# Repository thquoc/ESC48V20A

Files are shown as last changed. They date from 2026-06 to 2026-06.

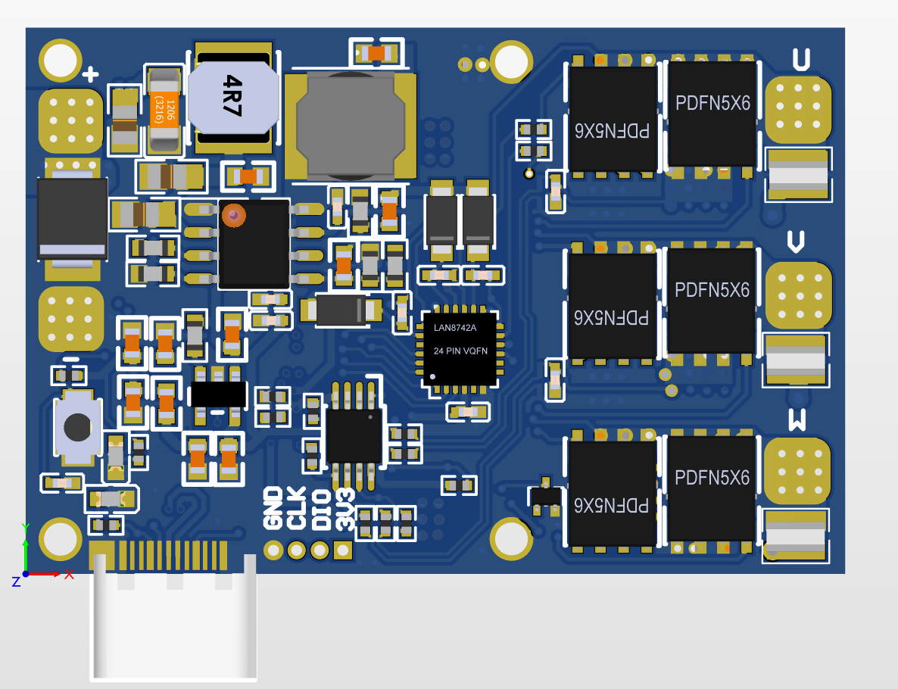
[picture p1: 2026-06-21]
3D-TOP.png

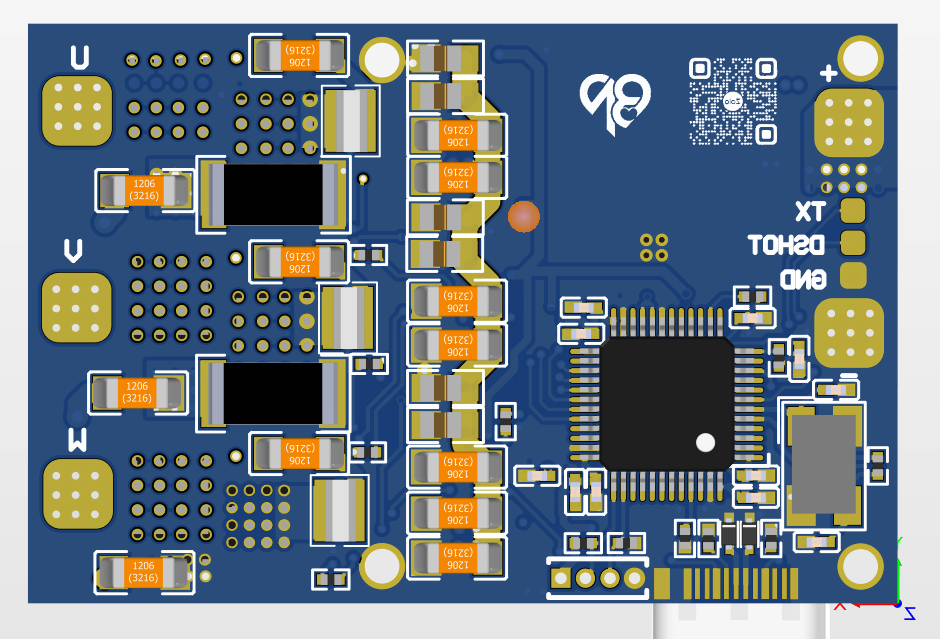
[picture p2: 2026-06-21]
3D-BOT.png

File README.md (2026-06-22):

| Thông số |Tham chiếu  | Giá trị |
|-----|---|---|
| Supply Voltage  | PVDD | 48V |
| Current | Dòng liên tục | 20A |
| IMAX | Dòng đỉnh khi kẹt tải  | 40A |
| Sense registor | Rsense | 2mΩ |
| Mosfet Qg(type)  | Qg | 60nC |
| Mosfet Rds  | Rds | 2.8mΩ tại 25℃ |
|Switching frequency| fsw | 20kHz |
|Gate resistance| Rgate | 16Ω |
|Amplifier reference| Vref | 3.3V|
|Amplifier gain| Gain | 20v/V |

------------------------------------------------------------------------------------
Note: Bạn thay đổi điện trở của ompap để có giá trị gain 20v/v. Thay Rsense = 2mΩ để cân bằng giữa nhiệt và sai số do nhiễu. Trong Documentation mình có đề cập đến cách ước tính.

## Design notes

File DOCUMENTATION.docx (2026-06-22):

DOCUMENTATION

1. Tính Rshunt để nhiệt lượng tỏa ra là thấp nhất nhưng vẫn đủ độ phân giải cho FOC.
- Dòng đo tối đa 40A, dòng liên tục 20A.
- I_(LSB) =(v_(ref))/(2^12 *Gain* R_(shunt))
- R_(shunt) =(V_(ref))/(2*I_(max) *Gain)
- Để đo dòng hai chiều trong động cơ 3 phase(dòng -, và +) tại Vref = 3.3V, ta chọn Voffset = 1.65V.

Tính tổn hao trên điện trở shunt: P = Irms^2 *Rshunt = 20*Rshunt.

- Tại Gain = 10, Rshunt = 5mΩ, P = 2W
- Tại Gain = 20, Rshunt = 2mΩ, P = 0.8W.
- Tại Gain = 40, Rshunt = 1mΩ, P = 0.4W.
- Để tối ưu về nhiệt, và sai số do nhiễu mình chọn Gain tại 20 và Rshunt = 2mΩ
2. Ước lượng nội trở Rds tối đa cho phép để mạch không quá nhiệt khi hoạt động liên tục.
- P tổn hao(Ptot) = P tổn hao dẫn(Pcond) + P chuyển mạch (Psw). Ở đây để tính Psw mình cần các giá trị cụ thể như Qg, Qrr, tf, tr... của một mosfet cụ thể. Nên trong trường hợp này ta chỉ ước lượng tương đối. Sau khi đã chọn được mosfet thích hợp mình sẽ tính lại Psw, sau đó sẽ đưa ra phương án tản nhiệt trên pcb cho mosfet.

Bảng ước lượng nhanh:

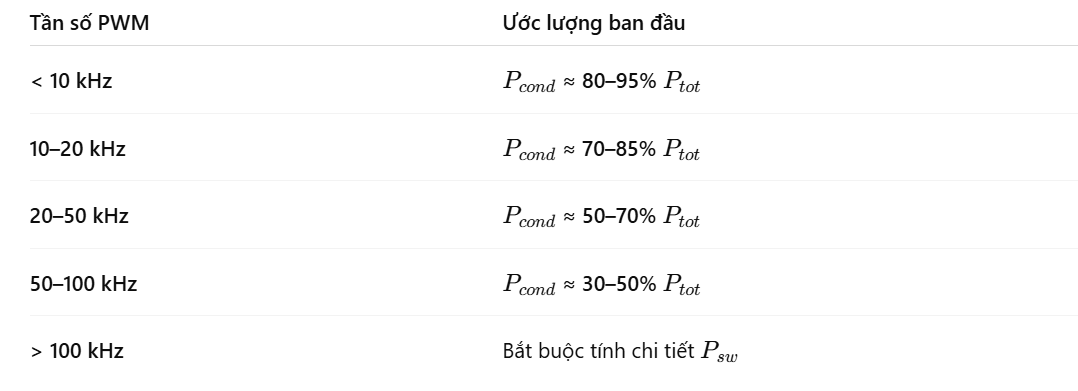
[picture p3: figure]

(Cái này mình tham khảo chat nha)

- Tại tần số 20khz, Pcond = 80% Ptot, Ptot = Pcond/0.75= (Rds.Irms^2)/0.75.

Moset không quá nhiệt khi hoạt động liên tục đối với esc drone:

- Ta = 40 độ C.
- Tj = 90 độ C.
- RθJA = 25 ℃/W(giá trị ước lượng).
- Ptot = ∆T/ RθJA = 50/25 = 2W, suy ra Pcond khoảng 1.4W.
- Rds(90) = Pcond/Irms^2 = 1.4/20^2 = 4mΩ.

Bảng ước lượng KT:

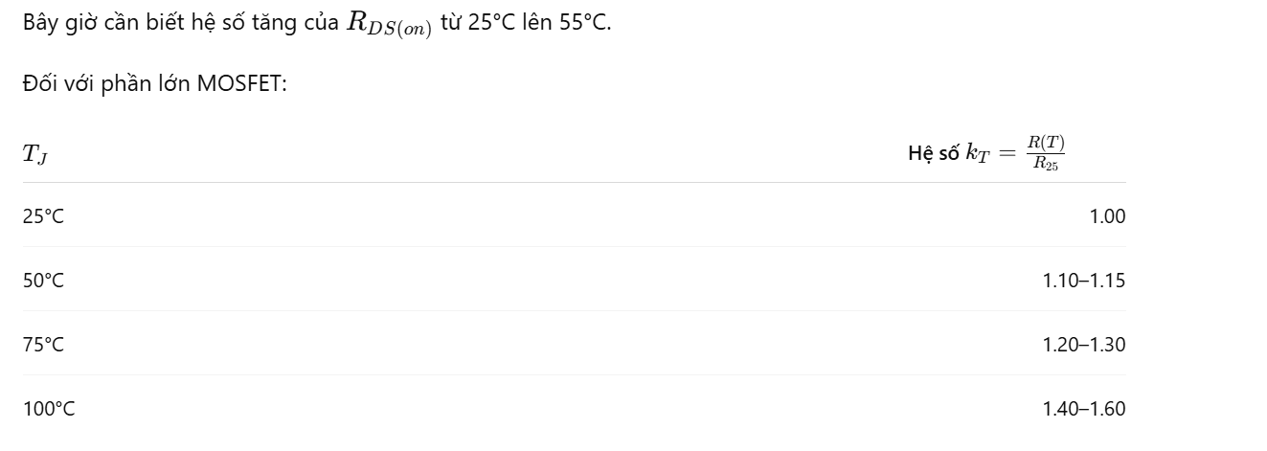
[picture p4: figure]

(Cái này mình cũng tham khảo chat nha).

- Rds(25) = R(90)/KT= 4/1.4 = 2.86mΩ, suy ra, Rds(25) max khoảng 2.9mΩ.
3. Ước lượng Dboot.

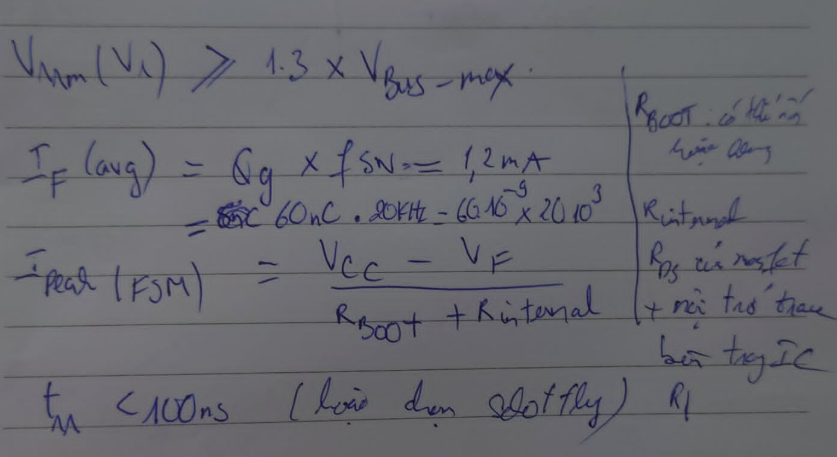
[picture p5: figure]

4. Tính Cboot cho drv.
- Tính ∆Vbst:

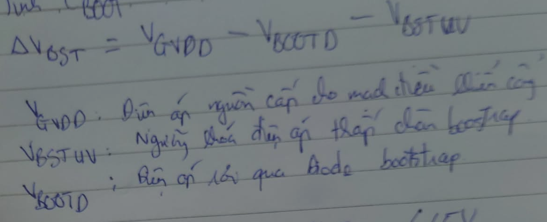
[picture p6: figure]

- ∆Vbst = 12 – 0.85 -4.5 = 6.65V.
- Qtotal:

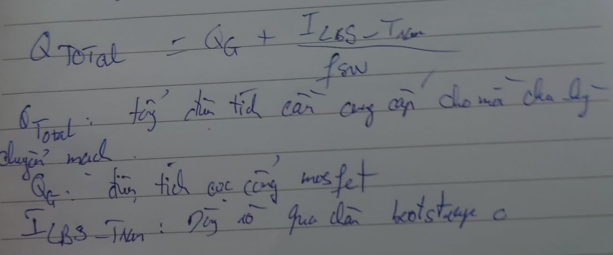
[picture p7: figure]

- Qtotal = 60nC + 11nC = 71nC
- Tính Cboot

Note: Các bước tính Psw các bạn tham khảo trong tài liệu này: infineon-70-41484-applicationnotes. Tài liệu này mình lưu trong mục datasheet.

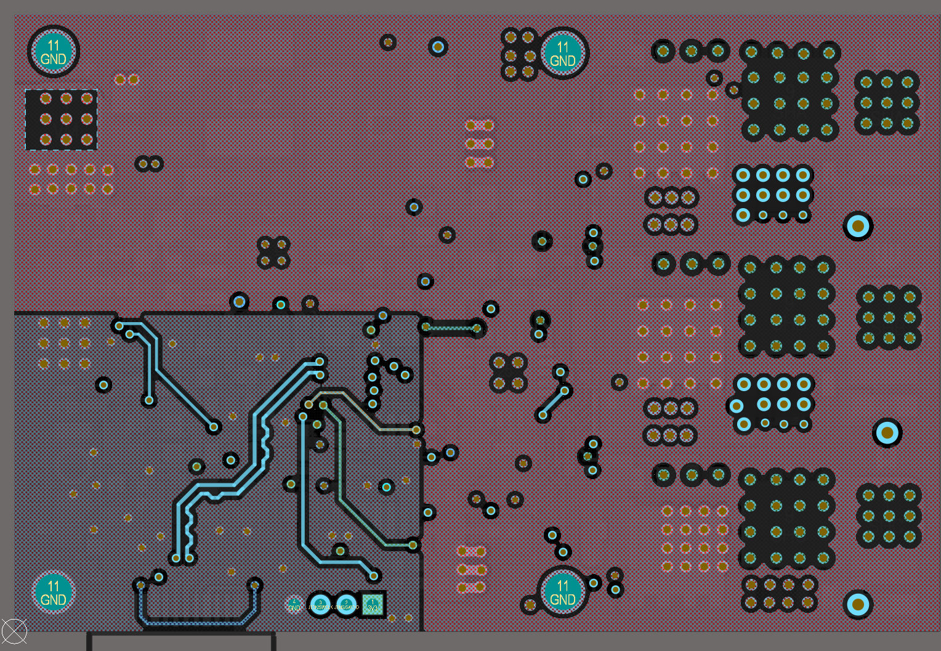
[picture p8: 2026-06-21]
L3-PWR.png

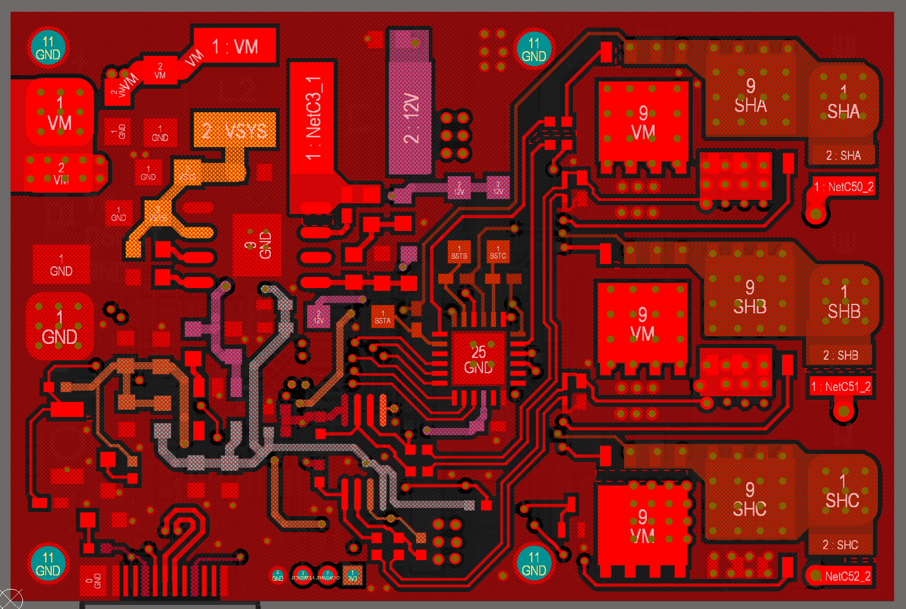
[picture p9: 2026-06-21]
TOP.png

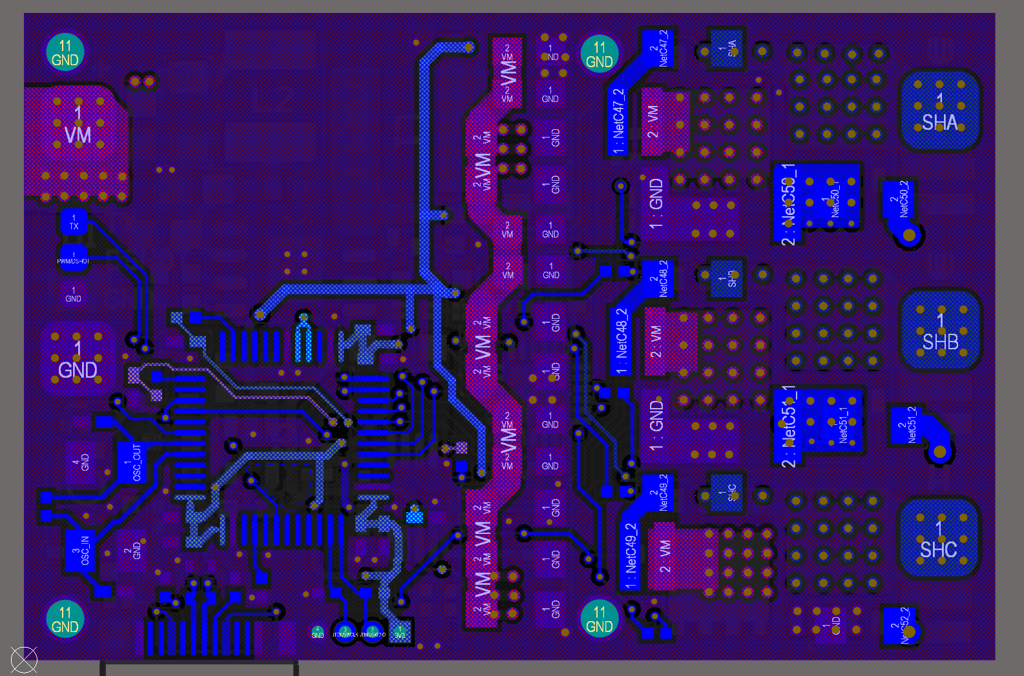
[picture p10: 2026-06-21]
BOT.png

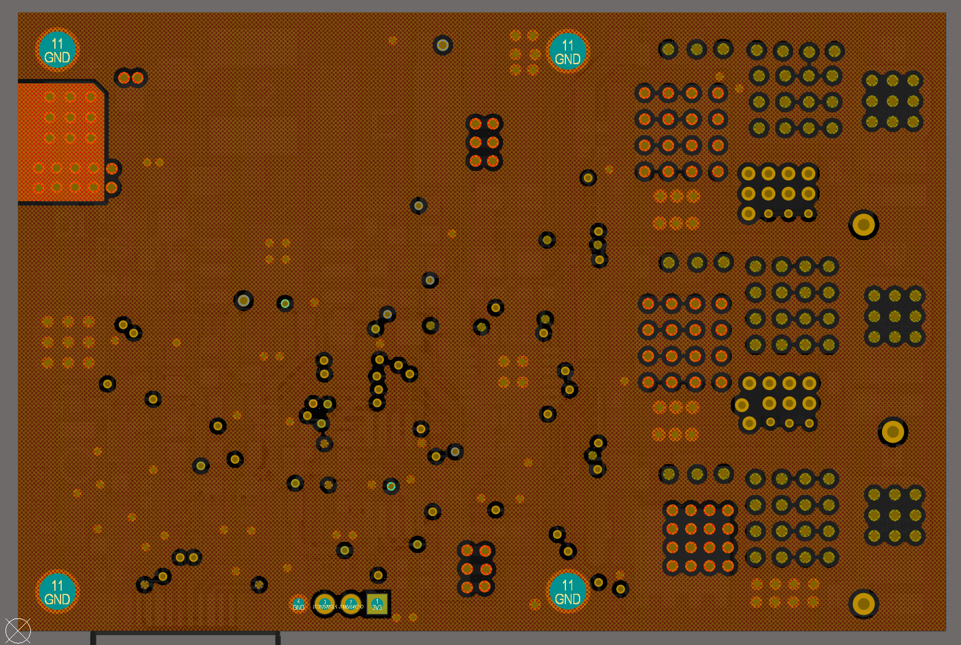
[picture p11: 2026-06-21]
L2-GND.png

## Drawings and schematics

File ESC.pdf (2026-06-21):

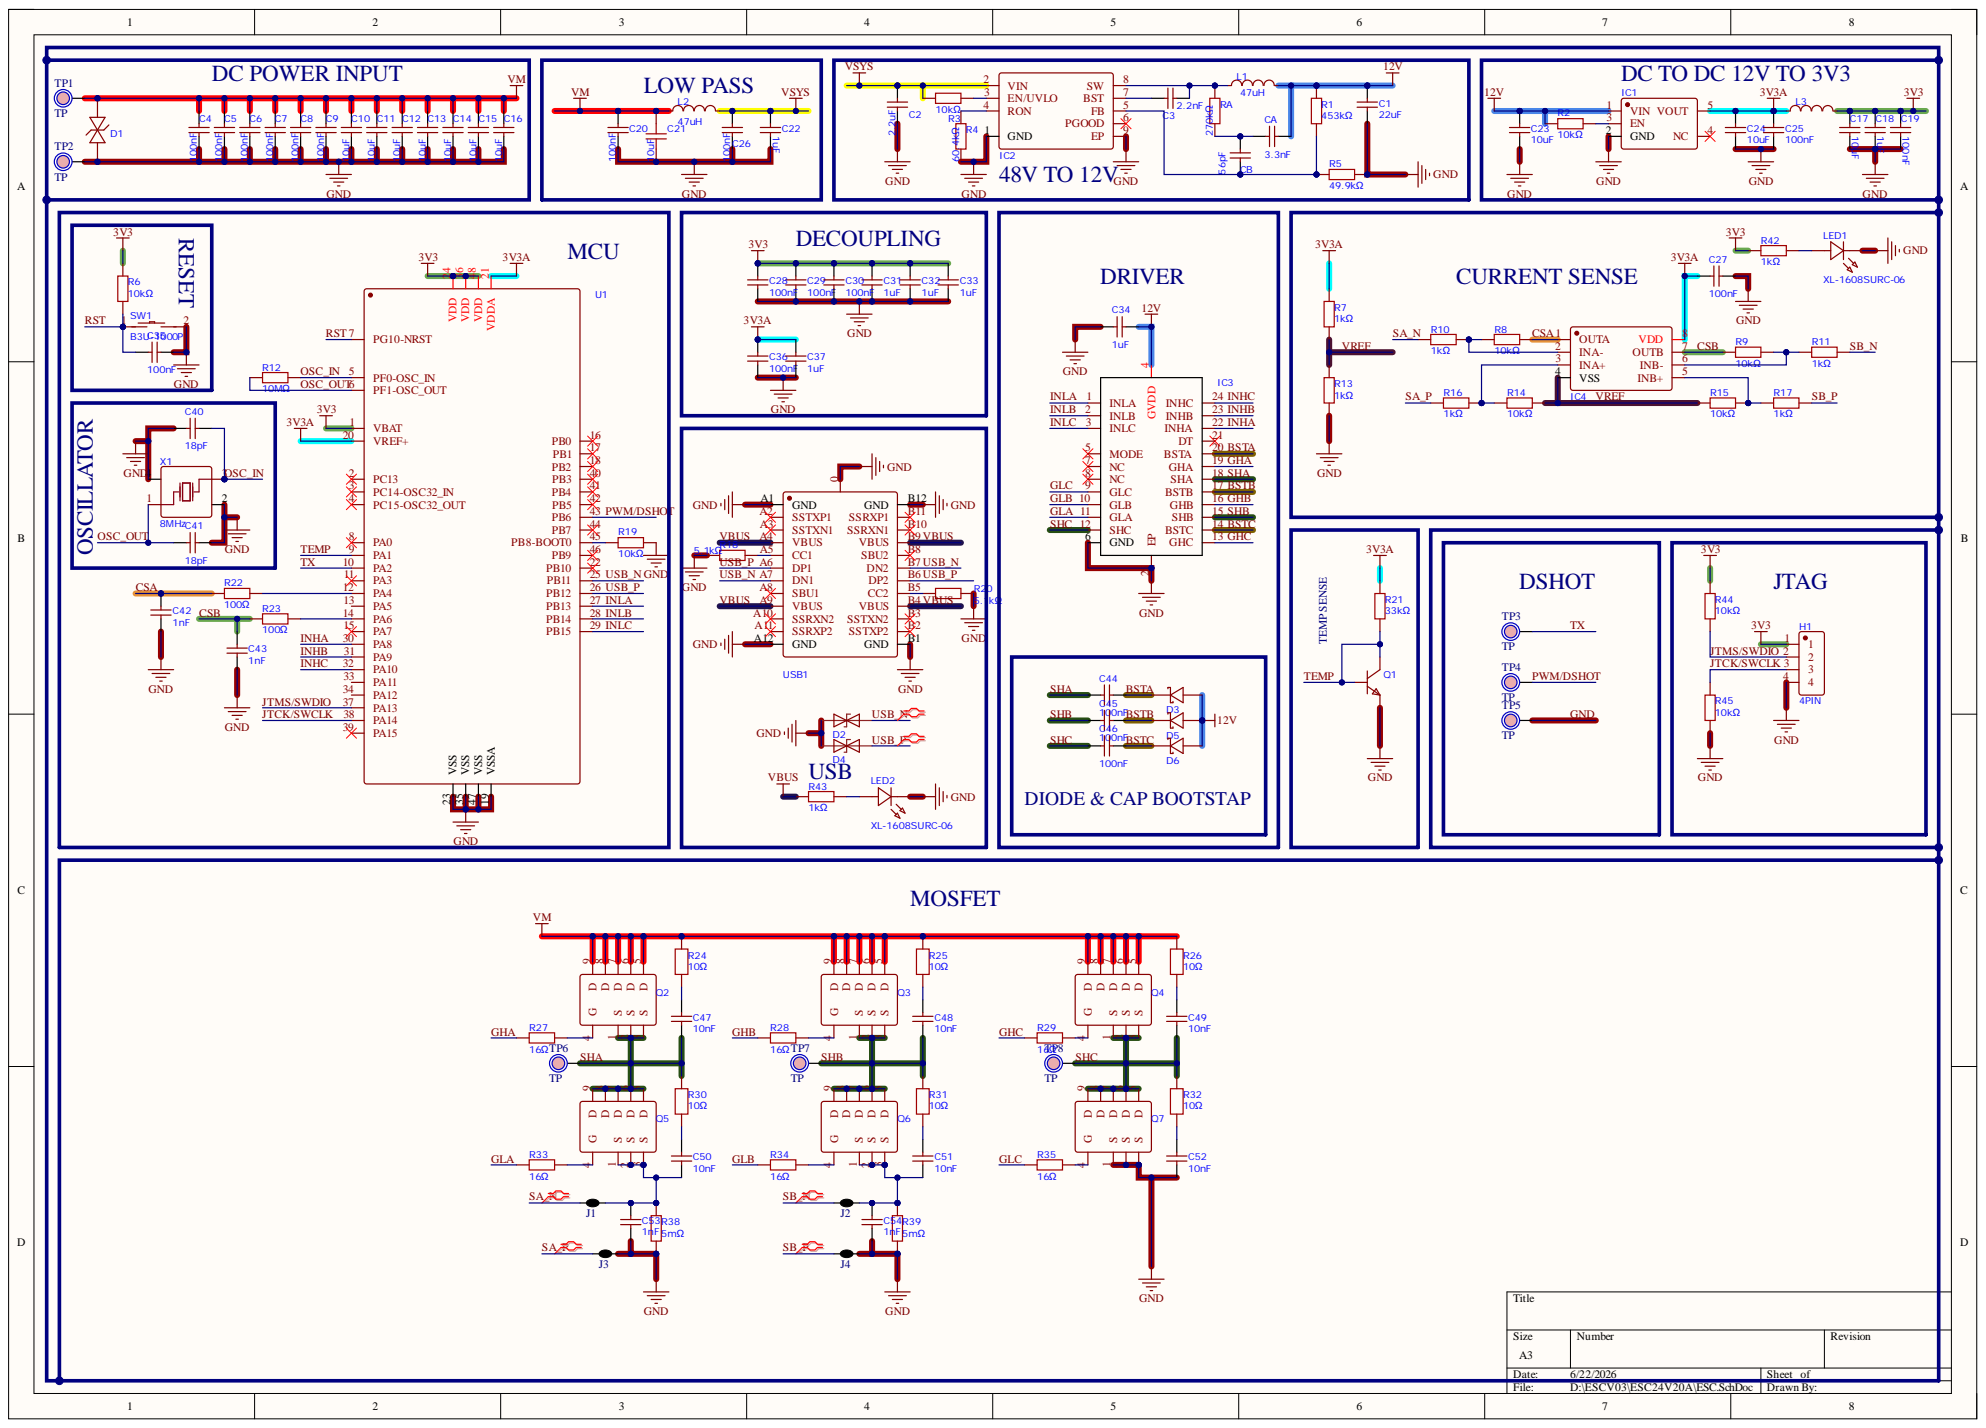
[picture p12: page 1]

VSSA 19 VDDA 21 VDD 48 VDD 36 VDD 24

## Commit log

2026-06-22 update documentation
    [ESCV03.PrjPcb]
2026-06-22 note
    Added note about changing resistor for gain adjustment.
2026-06-22 update readme
    Updated Rsense value to 2mΩ in specifications and added note about balancing thermal and noise errors.
